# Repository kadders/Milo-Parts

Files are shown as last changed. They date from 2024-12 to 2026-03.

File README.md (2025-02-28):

# Milo Parts Collection

This repository contains various Milo parts and and tooling in STEP file format.

## Vices, Components & Workholding

- [Z-Y Rail Nut v7](T-nuts/Z-Y%20Rail%20Nut%20v7.step) - Rail nut component for Z and Y axis mounting
- [Vice Angle Plate v6](Vices/Angle%20Vice%20Plate/Vice%20Angle%20Plate%20v6.step) - Angle plate for Inception Vice
- [Vice Angle Plate v5](Vices/Angle%20Vice%20Plate/Vice%20Angle%20Plate%20v5.step) - Angle plate for SMW Vice (use with soft jaws)
- [Soft Jaws](Vices/Soft-Jaws/Soft%20Jaws.step) - Protective soft jaws for workholding
- [Jaw Face](Vices/jaw-faces/Jaw%20Face.step) - Replacement face plates for machine vise jaws
- [Vice Collection](Vices/Vice%20Collection.step) - Complete collection of vice bases and vice faces
### Material Requirements

See [Bill of Materials](BOM.md) for detailed material requirements and quantities.

## Tooling & Cutting Tools

- [Tooling](tools/.tools) - Tooling Library Based off the tools from the LDO kit as well as some additional tools.

- For comprehensive information regarding speeds, feeds, and the tooling utilized, please refer to the README files of the respective project repositories.

## Contributing

Feel free to submit issues or pull requests if you have improvements or modifications to any of the parts.

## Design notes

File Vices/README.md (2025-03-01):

# Vices Documentation

This directory contains various vice components and their respective STEP files for reference and use.

## Available Vice Parts
- [Angle Vice Plate](Angle%20Vice%20Plate/) - A plate designed for setting up angles on the vices.
- [Soft Jaws](Soft-Jaws/) - Protective soft jaws for workholding.
- [Jaw Face](jaw-faces/) - Replacement face inserts for vise jaws.
- [Vice Collection](vice-collection/) - A complete collection of vice bases and vice jaws (both small and large) as well as a few other components.

## Additional Documentation

- For detailed operation instructions for the Soft Jaws, refer to the [Soft Jaws README](Soft-Jaws/README.md).

(More documentation will be added as I get time)

Feel free to explore the files and documentation for more information on each component.

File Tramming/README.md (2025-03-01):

# Tramming Tool Documentation

## Tramming Tool
- **Quantity**: 1 piece
- **Stock Material**: ABS/PLA (I used ABS)
- **Print Orientation**: Flat Side down, the 4 holes on the side of the part facing up from the bed.
- **Fasteners**:
  - 2x M5x8mm Ball point grub screw (For securing one or more Dial Indicators)
  - 1x 5mm rod (threaded as one end ~6mm) (For securing the Tramming Tool to the spindle collet)
  - 1x 5mm collet (For holding the 5mm rod in place in the spindle, you might be able to get away with a 6mm collet)

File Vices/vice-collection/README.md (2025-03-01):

# Vice Collection Documentation

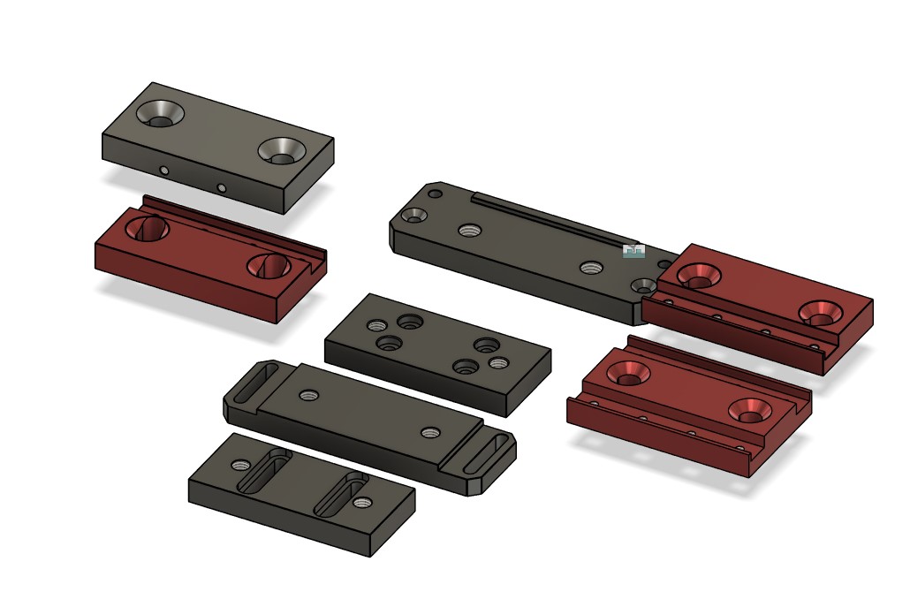
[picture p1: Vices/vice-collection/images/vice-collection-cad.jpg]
Vice Collection CAD Model


## Overview
The Vice Collection includes a complete set of vice bases and vice jaws (both small and large) designed for precision workholding in machining operations. These components provide reliable clamping force while maintaining accuracy for various machining tasks.

## Components
- **Vice Bases**:
  - **Small Sliding Base**: Compact sliding foundation for smaller workpieces
  - **Large Sliding Base**: Full-sized sliding foundation for larger projects
  - **Small Rigid Base**: Fixed compact base for maximum stability with smaller stock footprint.
  - **Large Rigid Base**: Fixed full-sized base for maximum stability with larger stock footprint.
- **Vice Jaws**: For holding larger workpieces

## Material Requirements
- **Vice Bases**: Aluminum 6061-T6 (for lightweight rigidity and excellent machinability)
   - **Small Base**: 25x50x100mm
   - **Large Base**: 50x50x150mm
- **Vice Jaws**: Aluminum 6061-T6 (for lightweight rigidity and excellent machinability)
   - **Jaws**: 25x50x100mm
- **Double Jaws**: Aluminum 6061-T6 (for lightweight rigidity and excellent machinability)
   - **Double Jaws**: 25x75x100mm
- **Fasteners**: 
  - M10x30mm Socket Head Cap Screws (for mounting vice jaws to vice base)
  - M5x12mm Socket Head Cap Screws (for mounting jaw faces, these are called out in the jaw face documentation)

## Features
- Compatible with [Soft Jaws](../Soft-Jaws/) for delicate parts
- Replaceable [Jaw Faces](../jaw-faces/) for when surfaces become worn
- Can be used with the [Angle Vice Plate](../Angle%20Vice%20Plate/) for angled setups

## Installation Instructions
1. Clean the machine table surface thoroughly
2. Align the vice base with T-slots on the machine table
3. Secure using appropriate T-slot nuts and bolts
4. Verify the vice is properly aligned using a dial indicator
5. Install desired jaw faces as needed for the specific operation

## Maintenance
- Regularly clean and lubricate moving parts
- Check for wear on jaw faces and replace as needed
- Verify alignment periodically to ensure continued precision
- Remove chips and debris after each use

## Machining Resources
Machining resources for the vice collection is currently in the works and will be added soon.

## Additional Resources
For further information on other vice components, please refer to the [Vices Documentation](../README.md).

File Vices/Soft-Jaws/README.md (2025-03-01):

# Soft Jaws Documentation

## Overview
The Soft Jaws are designed to provide gentle but secure workholding for delicate or finished parts. They protect workpieces from marring or damage that might occur with standard metal jaws, while still maintaining precision during machining operations.

## Material Requirements
- **Quantity**: 2 pieces (1 pair)
- **Stock Material**: Aluminum 6061-T6 (recommended for durability and precision)
- **Fasteners**: 
  - 2x M10x30mm Counter-Sunk Screws (for mounting to vice, per jaw)

## Features
- Non-marring surface for delicate workpieces
- Custom profiles can be machined into the jaws for specific part geometries
- Compatible with the [Vice Collection](../vice-collection/) vices
- Replaceable design for when jaws become worn or damaged

## Installation Instructions
1. Remove the existing jaw faces from the vise.
2. Align the soft jaws with the mounting holes on the vice.
3. Secure using the M10x30mm Counter-Sunk Screws.
4. Ensure the jaws are properly seated and tightened before use.

## Customization
The soft jaws can be machined to create custom profiles for specific workpieces:
- Use the machining resources provided in [Machining Resources.md](Machining%20Resources.md) for tooling and machining steps that worked well for the soft jaws.
- Follow the recommended toolpaths and settings for optimal results
- Consider creating multiple sets of soft jaws for different workpiece geometries

## Maintenance
- Regularly inspect the soft jaws for wear, damage, or embedded chips
- Clean the jaw surfaces after each use to prevent material buildup
- Replace when worn or damaged to maintain precision in workholding

## Additional Resources
For further information on other vice parts, please refer to the [Vices Documentation](../README.md).

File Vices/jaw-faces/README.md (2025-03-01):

# Jaw Faces Documentation

## Overview
The Jaw Faces are replacement face plates designed for the [Vice Collection](../Vice%20Collection.step) and SMW Vices. They provide a secure and stable surface for workholding, ensuring precision and accuracy during machining operations.

## Material Requirements
- **Quantity**: 1 piece
- **Stock Material**: Aluminum 6061-T6 (100mm x 25mm x 50mm)
- **Fasteners**: 
  - 4x M5x10mm Socket Head Cap Screws (for mounting to vice, per jaw face)

## Installation Instructions
1. Remove the existing jaw faces from the vise.
2. Align the new jaw face with the mounting holes.
3. Secure the jaw face using the appropriate fasteners.
4. Ensure the jaw face is flush with the vise for optimal performance.

## Maintenance
- Regularly inspect the jaw faces for wear and damage.
- Clean the jaw faces after each use to prevent material buildup.
- Replace jaw faces as needed to maintain precision in workholding.

## Additional Resources
For further information on operation and usage, please refer to the [Vices Documentation](../README.md).

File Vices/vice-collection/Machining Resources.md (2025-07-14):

# Top Jaw Documentation

## Operation Overview
- **Operation Name:** Face1
- **Toolpath Type:** Linearized circular move - low memory mode enabled

## Operation 1 Details

### Tool 1: 3 Flute DLC
- **Tool Number:** T9
- **Tool Size:** 6mm
- **RPM:** 15,000
- **Feed Rate:** 333.3 mm/min (for Z movement)
- **Operation Type:** Face Milling with Adaptive Pass
- **Coolant:** Mist (M7)
- **Variable Spindle Speed Control:** Enabled (P4000 V200)
- **Adaptive Pass:** Involves multiple passes with complex contour following, allowing for efficient material removal while maintaining consistent engagement with the workpiece.

### Tool 2: 4.2mm Drill
- **Tool Number:** T11
- **Tool Size:** 4.2mm
- **RPM:** 12,000
- **Feed Rate:** Not specified in the provided G-code.
- **Operation Type:** Drilling
- **Coolant:** Mist (M7)
- **Variable Spindle Speed Control:** Enabled (P4000 V200)

### Tool 3: Double Flute 3mm Ball
- **Tool Number:** T2
- **Tool Size:** 3mm
- **RPM:** 10,000
- **Feed Rate:** Not specified in the provided G-code.
- **Operation Type:** Scallop
- **Coolant:** Mist (M7)
- **Variable Spindle Speed Control:** Enabled (P4000 V200)

### Tool 4: Chamfer Mill
- **Tool Number:** T6
- **Tool Size:** 6mm
- **RPM:** 20,000
- **Feed Rate:** 333.3 mm/min
- **Operation Type:** 2D Chamfer
- **Coolant:** Mist (M7)
- **Variable Spindle Speed Control:** Enabled (P4000 V200)

### Tool 5: M5x0.8mm Thread Mill
- **Tool Number:** T17
- **Tool Size:** M5x0.8mm
- **RPM:** 6,000
- **Feed Rate:** Not specified in the provided G-code.
- **Operation Type:** Thread Milling
- **Coolant:** Mist (M7)
- **Variable Spindle Speed Control:** Enabled (P4000 V200)

## Operation 2 Details

### Tool 1: 3 Flute DLC
- **Tool Number:** T9
- **Tool Size:** 6mm
- **RPM:** 15,000
- **Feed Rate:** 333.3 mm/min (for Z movement)
- **Operation Type:** Face Milling with Adaptive Pass
- **Coolant:** Mist (M7)
- **Variable Spindle Speed Control:** Enabled (P4000 V200)
- **Adaptive Pass:** Involves multiple passes with complex contour following, allowing for efficient material removal while maintaining consistent engagement with the workpiece.

### Tool 2: Chamfer Mill
- **Tool Number:** T6
- **Tool Size:** 6mm
- **RPM:** 20,000
- **Feed Rate:** 333.3 mm/min
- **Operation Type:** 2D Chamfer
- **Coolant:** Mist (M7)
- **Variable Spindle Speed Control:** Enabled (P4000 V200)

## Summary of Operations
1. **Initial Setup and Probing:**
   - Probes reference surface.
   - Uses WCS 1 (G54).
   - Probes origin in current WCS.
   - Enables rotation compensation.

2. **Main Operation (Tool 1 - T9):**
   - **Type:** Face Milling with Adaptive Pass
   - **RPM:** 15,000
   - **Feed Rate:** 333.3 mm/min
   - **Operation:** Multiple passes with complex contour following, including adaptive milling strategies.

3. **Secondary Operations (Tool 2 - T11):**
   - **Type:** Drilling
   - **RPM:** 12,000
   - **Feed Rate:** Not specified.
   - **Operation:** Drilling operations as needed.

4. **Additional Operations (Tool 3 - T2):**
   - **Type:** Scallop
   - **RPM:** 10,000
   - **Feed Rate:** Not specified.
   - **Operation:** Scalloping as part of the machining process.

5. **Chamfer Operation (Tool 4 - T6):**
   - **Type:** 2D Chamfer
   - **RPM:** 20,000
   - **Feed Rate:** 333.3 mm/min
   - **Operation:** Chamfering around the perimeter.

6. **Threading Operation (Tool 5 - T17):**
   - **Type:** Thread Milling
   - **RPM:** 6,000
   - **Feed Rate:** Not specified.
   - **Operation:** Thread milling as required.

## Additional Notes
- The operation includes extensive safety checks and spindle controls.
- The G-code is designed for a specific firmware configuration (RRF) and includes automatic probing and work coordinate system management.
- The operation features multiple tool changes and complex machining paths.

# Machining Details for Large Sliding Base - Op1

### Steps:
1. **Initial Setup:**
   - Probes reference surface.
   - Switch to WCS 1 (G54).
   - Probes origin in current WCS.
   - Enables rotation compensation.

2. **Starting Position:**
   - Move to starting position in X and Y: `G0 X54.01 Y-2.395`
   - Move to starting position in Z: `G0 Z15.0`

3. **Engage Tool:**
   - Move down to Z position: `G1 Z-2.1 F333.3`

4. **Face Milling Operation:**
   - Perform linearized circular moves to mill the face:
     - `G1 X54.003 Z-2.194 F2000.0`
     - Continue with a series of linear moves to create the desired contour.

5. **Adaptive Pass:**
   - Execute adaptive milling strategies with multiple passes to efficiently remove material while maintaining consistent engagement with the workpiece.

6. **Final Positioning:**
   - Return to Z position: `G0 Z5.0`
   - Move to a new X and Y position: `G0 X10.896 Y138.867`
   - Engage tool again: `G1 Z-7.175 F333.3`
   - Perform additional milling operations as needed.

### Tool 1: 3 Flute DLC
- **Tool Number:** T9
- **Tool Size:** 6mm
- **RPM:** 15,000
- **Feed Rate:** 333.3 mm/min (for Z movement)
- **Operation Type:** Face Milling with Adaptive Pass
- **Coolant:** Mist (M7)
- **Variable Spindle Speed Control:** Enabled (P4000 V200)

### Tool 2: Single Flute 3mm
- **Tool Number:** T1
- **Tool Size:** 3mm
- **RPM:** Not specified in the G-code.
- **Feed Rate:** Not specified in the G-code.
- **Operation Type:** Not explicitly defined in the provided G-code.
- **Coolant:** Mist (M7)
- **Variable Spindle Speed Control:** Enabled (P4000 V200)

#### Steps:
1. **Engage Tool:**
   - Tool is passed to firmware but not explicitly used in the provided G-code.

### Tool 3: Chamfer Mill
- **Tool Number:** T6
- **Tool Size:** 6mm
- **RPM:** Not specified in the G-code.
- **Feed Rate:** Not specified in the G-code.
- **Operation Type:** Chamfering
- **Coolant:** Mist (M7)
- **Variable Spindle Speed Control:** Enabled (P4000 V200)

#### Steps:
1. **Engage Tool:**
   - Tool is passed to firmware but not explicitly used in the provided G-code.

## Summary of Operations
1. **Initial Setup and Probing:**
   - Probes reference surface.
   - Uses WCS 1 (G54).
   - Probes origin in current WCS.
   - Enables rotation compensation.

2. **Main Operation (Tool 1 - T9):**
   - **Type:** Face Milling with Adaptive Pass
   - **RPM:** 15,000
   - **Feed Rate:** 333.3 mm/min
   - **Operation:** Multiple passes with complex contour following, including adaptive milling strategies.

3. **Additional Operations:**
   - **Tool 2 (Single Flute 12mm):** Not explicitly used in the operation.
   - **Tool 3 (Chamfer Mill):** Not explicitly used in the operation.

## Additional Notes
- The operation includes extensive safety checks and spindle controls.
- The G-code is designed for a specific firmware configuration (RRF) and includes automatic probing and work coordinate system management.
- The operation features multiple tool changes and complex machining paths.

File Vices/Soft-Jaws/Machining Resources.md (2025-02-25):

# Vice Jaw Operation 1 Overview

## Tool Changes and Operations

### Tool 9 - 3 Flute DLC (6mm)
- **RPM**: 15,000
- **Feed Rate**: 2,000 mm/min
- **Operation**: Adaptive clearing
- **Coolant**: Mist (M7)
- **Variable Spindle Speed Control**: Enabled (P4000 V200)

### Tool 3 - Single Flute (12mm)
- **RPM**: 20,000
- **Feed Rate**: 1,000 mm/min
- **Operation**: Adaptive clearing
- **Coolant**: Mist (M7)
- **Variable Spindle Speed Control**: Enabled (P4000 V200)

### Tool 2 - Double Flute 17mm Ball
- **RPM**: 20,000
- **Feed Rate**: 960 mm/min
- **Operation**: Scallop
- **Coolant**: Mist (M7)
- **Variable Spindle Speed Control**: Enabled (P4000 V200)

### Tool 6 - Chamfer Mill (6mm)
- **RPM**: 20,000  
- **Feed Rate**: 2,000 mm/min
- **Operation**: 2D Chamfer
- **Coolant**: Mist (M7)
- **Variable Spindle Speed Control**: Enabled (P4000 V200)

## Process Overview
1. Initial setup and probing
   - Probes reference surface
   - Uses WCS 1 (G54)
   - Probes origin in current WCS
   - Enables rotation compensation

2. Main Adaptive Operation (Tool 9)
   - Multiple adaptive clearing passes
   - Complex contour following
   - Multiple Z-level operations

3. Secondary Adaptive Operations (Tool 3 & Tool 2)
   - Additional adaptive clearing passes
   - Complex contour following
   - Multiple Z-level operations

4. Chamfer Operation (Tool 6)
   - 2D chamfering around the perimeter
   - Single pass at -3mm depth

## Safety Features
- Firmware version check (v0.5.0-rc1)
- Tool details passed to firmware
- Spindle acceleration monitoring
- Variable speed control for vibration reduction
- Coolant control
- Automatic parking between operations

## Notes
- File includes extensive safety checks and spindle controls
- Uses RRF firmware-specific features
- Includes automatic probing and work coordinate system management
- Multiple parking and tool change operations
- Comprehensive coolant and spindle speed management

# Vice Jaw Operation 2 Overview

## Tool Changes and Operations

### Tool 1 - 3 Flute DLC (3mm)
- **RPM**: 15,000
- **Feed Rate**: 2,000 mm/min
- **Operation**: Adaptive clearing
- **Coolant**: Mist (M7)
- **Variable Spindle Speed Control**: Enabled (P4000 V200)

### Tool 6 - Chamfer Mill (3mm)
- **RPM**: 20,000
- **Feed Rate**: 2,000 mm/min
- **Plunge Feed**: 333.3 mm/min
- **Operation**: 2D Chamfer
- **Coolant**: Mist (M7)
- **Variable Spindle Speed Control**: Enabled (P4000 V200)

## Process Overview
1. Initial setup and probing
   - Probes reference surface
   - Uses WCS 1 (G54)
   - Probes origin in current WCS
   - Enables rotation compensation

2. Main Adaptive Operation (Tool 1)
   - Multiple adaptive clearing passes
   - Complex contour following
   - Multiple Z-level operations at -3.9mm, -8.4mm, -17.7mm depths

3. Chamfer Operation (Tool 6)
   - 2D chamfering around the perimeter
   - Single pass at -10.449mm depth
   - Includes both external and internal feature chamfering

## Safety Features
- Firmware version check (v0.5.0-rc1)
- Tool details passed to firmware
- Spindle acceleration monitoring
- Variable speed control for vibration reduction
- Coolant control
- Automatic parking between operations

## Notes
- Operation 2 focuses on the opposite side of the vice jaw
- Includes deeper cutting operations than Operation 1
- Multiple Z-level passes for material removal
- Comprehensive safety checks and spindle controls
- Uses RRF firmware-specific features
- Includes automatic probing and work coordinate system management

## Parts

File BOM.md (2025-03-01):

# Bill of Materials

## Vices & Workholding Components

### Jaw Faces
- Quantity: 3 pieces
- Stock Material: 25x50x100mm (per jaw face, up to three)
- Fasteners:
  - 8x M5x12 (For attaching the jaw faces to the vice jaw tops)
- Location: [Jaw Face](Vices/jaw-faces/Jaw%20Face.step)

### Soft Jaws
- Quantity: 1 set
- Stock Material: 25x50x100mm (Per Soft Jaw)
- Fasteners:
  - 2x M10x30 (For attaching the soft jaws to the vice jaw tops)
- Location: [Soft Jaws](Vices/Soft-Jaws/Soft%20Jaws.step)

### Vice Angle Plates
- Quantity: 1 piece
- Stock Material: 25x50x100mm
- Fasteners:
  - 4x M5x12 (For attaching the vice angle plate to the vice jaw tops)
  - 2x M3 Shoulder Bolt (4mm shoulder) for attaching the angle bars to the angle plate
  - 2x 2mm pin (For setting the angle of the angle bars)
- Location: 
  - [Inception Vice Angle Plate](Vices/Angle%20Vice%20Plate/Vice%20Angle%20Plate%20v6.step)
  - [SMW Vice Angle Plate](Vices/Angle%20Vice%20Plate/Vice%20Angle%20Plate%20v5.step)

### Vice Collection
- Quantity: 1 set (2 vice bases, 2 vice jaw tops)
- Stock Material: 
  - 25x50x100mm (For the vice bases and jaw tops)
  - 25x50x150mm for larger components (Large Sliding Base and Large rigid base)
- Fasteners:
  - 4x M10x30 (For attaching the vice jaw tops to the base)
  - 8x M5x12 (For attaching the jaw faces to the vice jaw tops)
- Note: Complete collection of vice bases and vice faces
- Location: [Vice Collection](Vices/Vice%20Collection.step)

### T-Nuts
- Quantity: As needed
- Stock Material: 25x50x100mm (can fit 4 T-nuts, two large and two small)
- Fasteners:
  - 16x M5x8 (For attaching the T-nuts, and also for fixturing the workpiece, if desired)
- Note: Includes supplemental workholding fixture in STEP file
- Location: [Z-Y Rail Nut](T-nuts/Z-Y%20Rail%20Nut%20v7.step)

### Tramming Tool
- Quantity: 1 piece
- Stock Material: 25x50x100mm (for the main body)
- Fasteners:
  - 2x M5x8mm Ball point grub screw (For securing one or more Dial Indicators)
  - 1x 5mm rod (threaded as one end ~6mm) (For the securing the Tramming Tool to the spindle collet)
  - 1x 5mm collet (For holding the 5mm rod in place in the spindle, you might be able to get away with a 6mm collet)
- Location: [Tramming Tool](Tramming/Tramming%20Tool.step)

## Reference
Material requirements sourced from README.md:

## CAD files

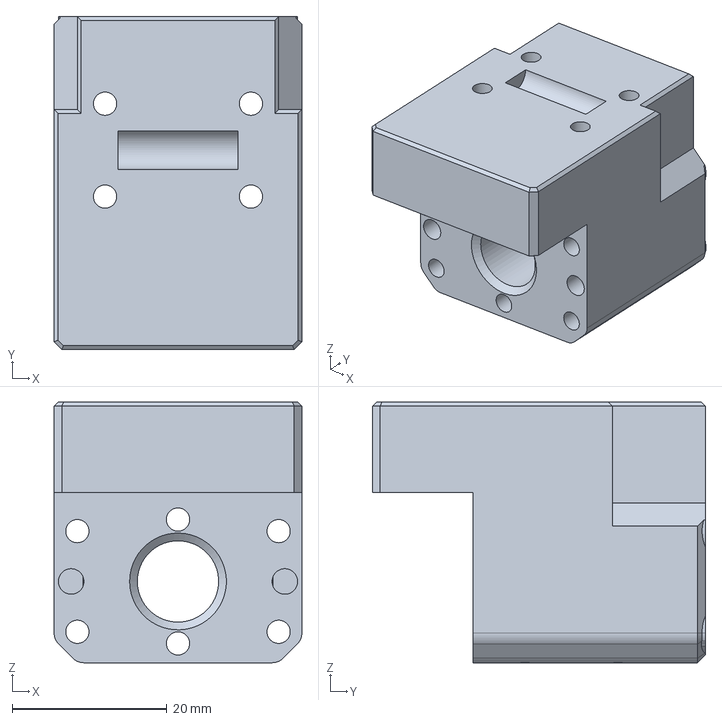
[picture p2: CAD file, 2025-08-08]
v1.6/AB Nut/ThrED-AB-Block-Assembly v39 v6.step
32.0 x 43.0 x 33.7 mm

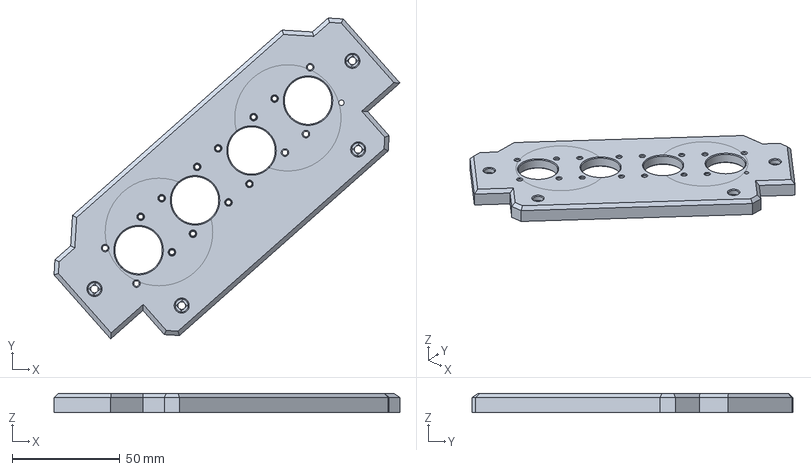
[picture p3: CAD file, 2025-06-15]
Casa/Electronics/Electronics passthru v6.step
160.8 x 149.1 x 9.00 mm

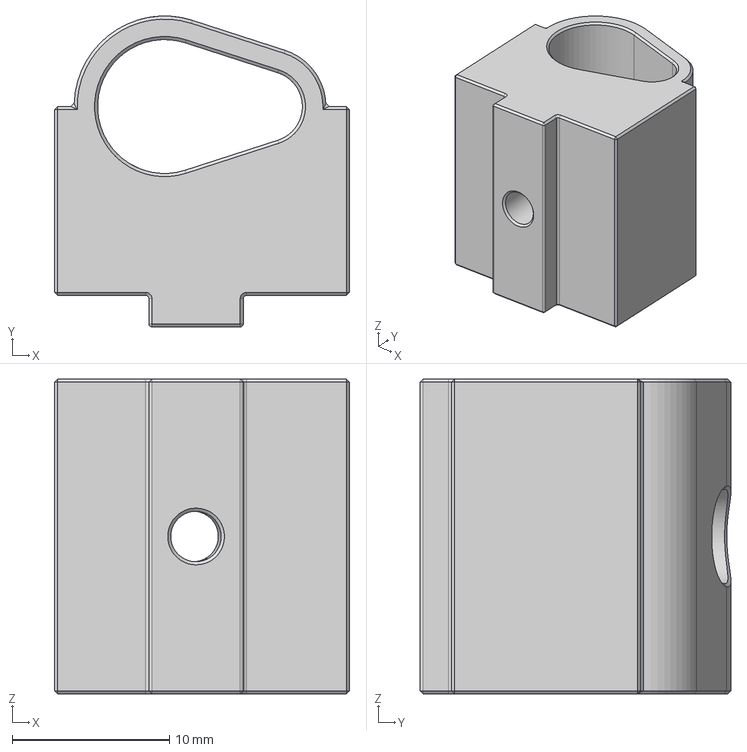
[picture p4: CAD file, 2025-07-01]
Casa/Misc/Air Line Holder.step
18.8 x 19.7 x 20.0 mm

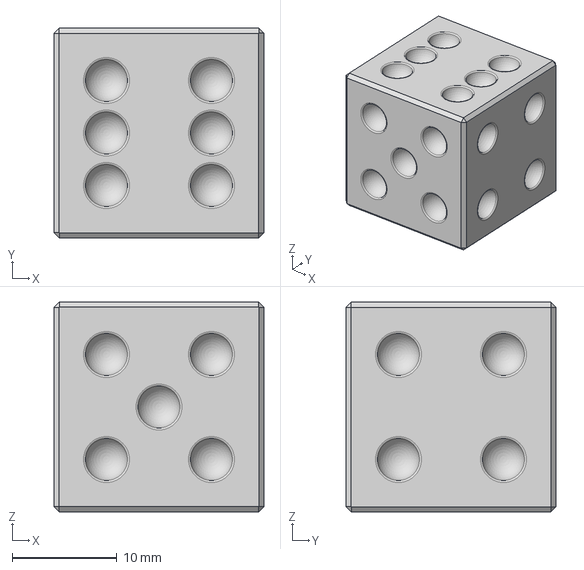
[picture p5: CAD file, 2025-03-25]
Dice/Dice.step
20.0 x 20.0 x 20.0 mm

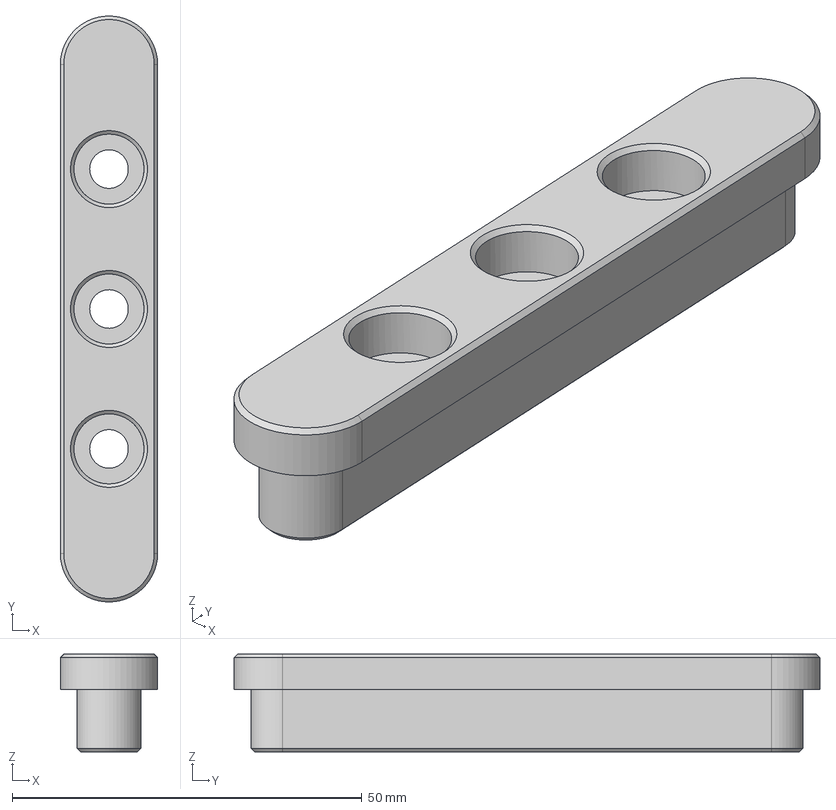
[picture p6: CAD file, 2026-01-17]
Hold Downs/SMW Hold Down.step
13.9 x 83.8 x 14.0 mm

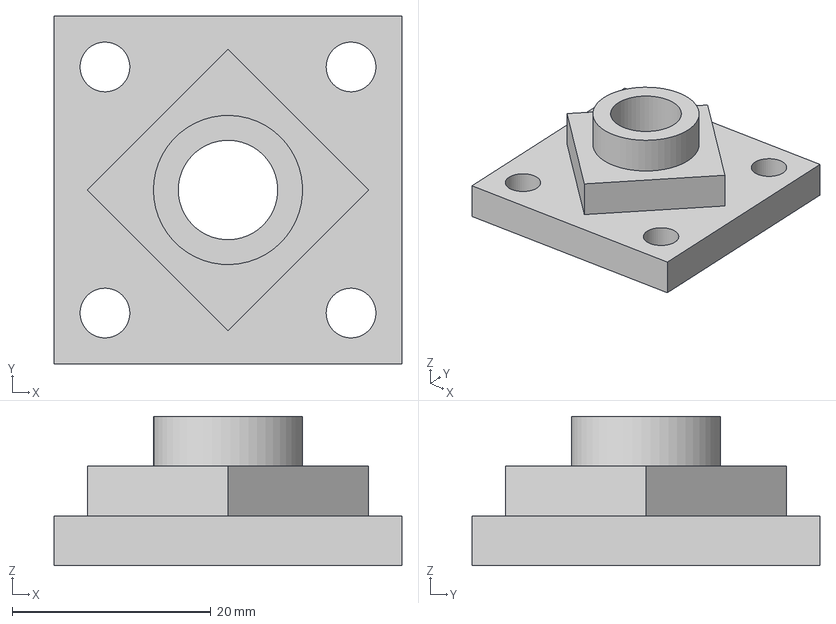
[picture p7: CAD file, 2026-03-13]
Test Part/Test BenCNC.step
35.0 x 35.0 x 15.0 mm

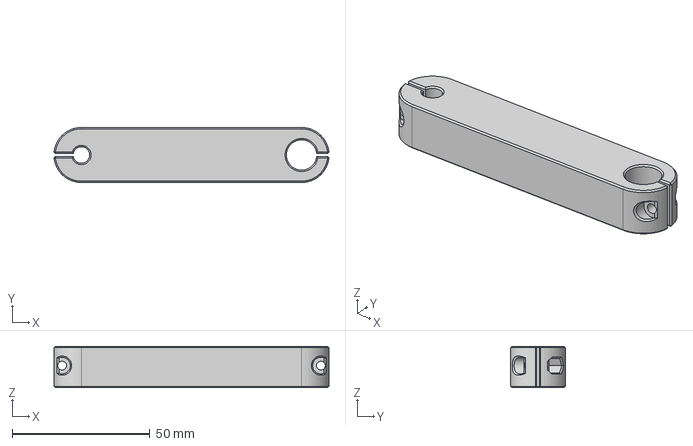
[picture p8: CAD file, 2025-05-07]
Tramming/Tram Swing Arm.step
99.9 x 20.0 x 15.0 mm

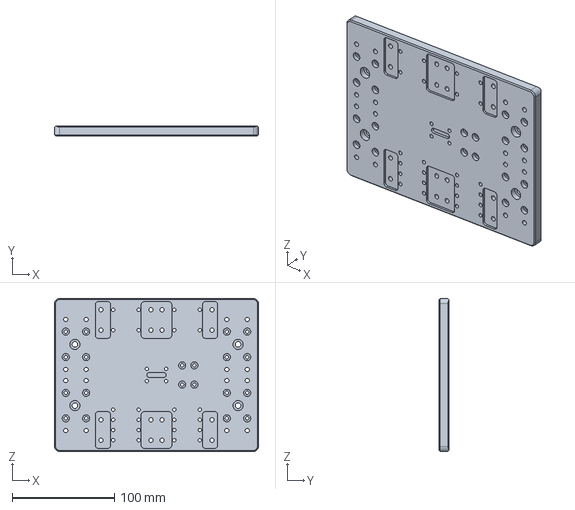
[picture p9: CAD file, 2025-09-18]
v1.6/X-Y Joiner Plate/X-to-Y-Joiner-Plate.step
200.0 x 9.60 x 150.0 mm

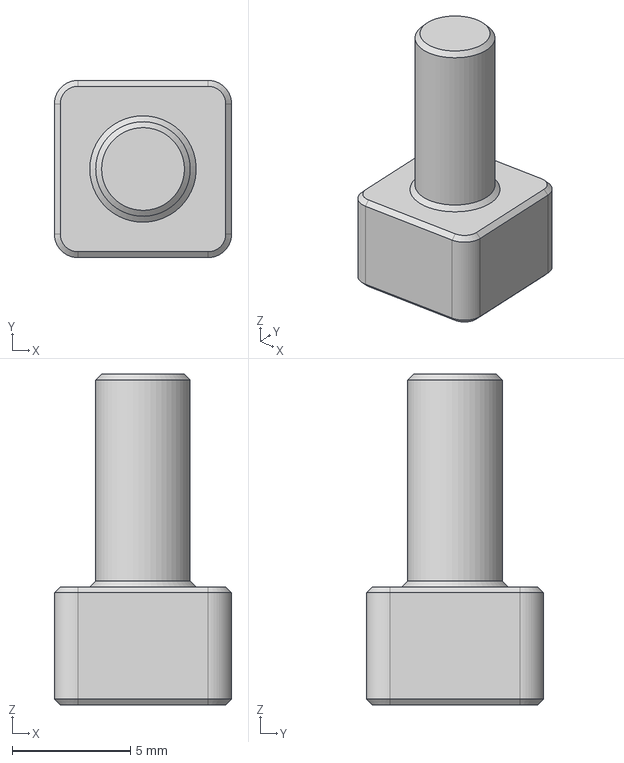
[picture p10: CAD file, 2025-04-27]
Vices/Angle Vice Plate/Angle Plate Stop.step
7.50 x 7.50 x 14.0 mm

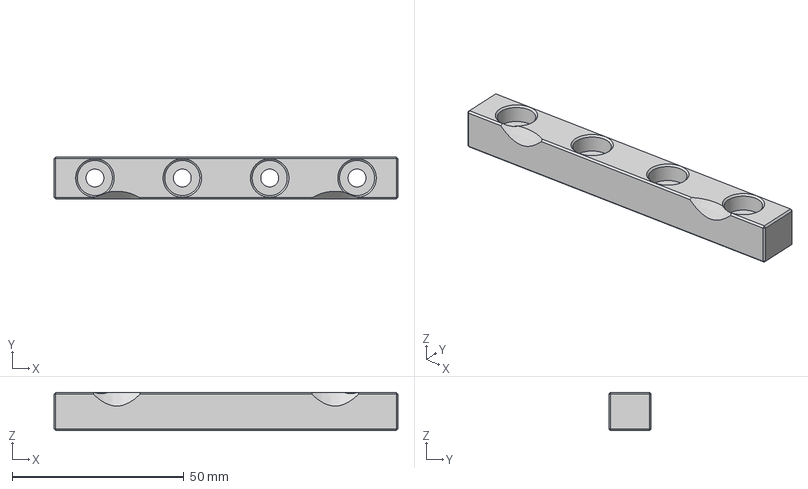
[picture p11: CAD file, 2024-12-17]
Vices/jaw-faces/Jaw Face.step
100.0 x 12.3 x 11.1 mm

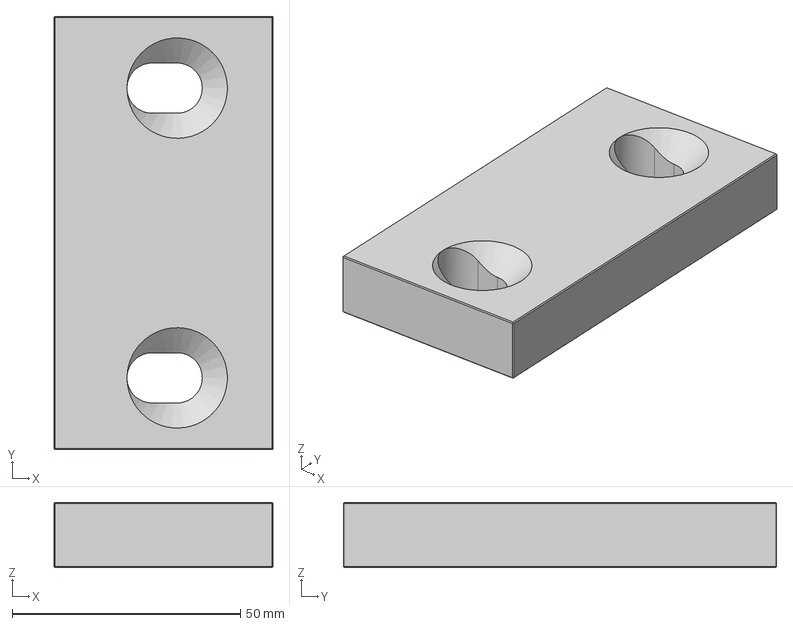
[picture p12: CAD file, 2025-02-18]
Vices/Soft-Jaws/Soft Jaws.step
48.0 x 95.0 x 14.4 mm

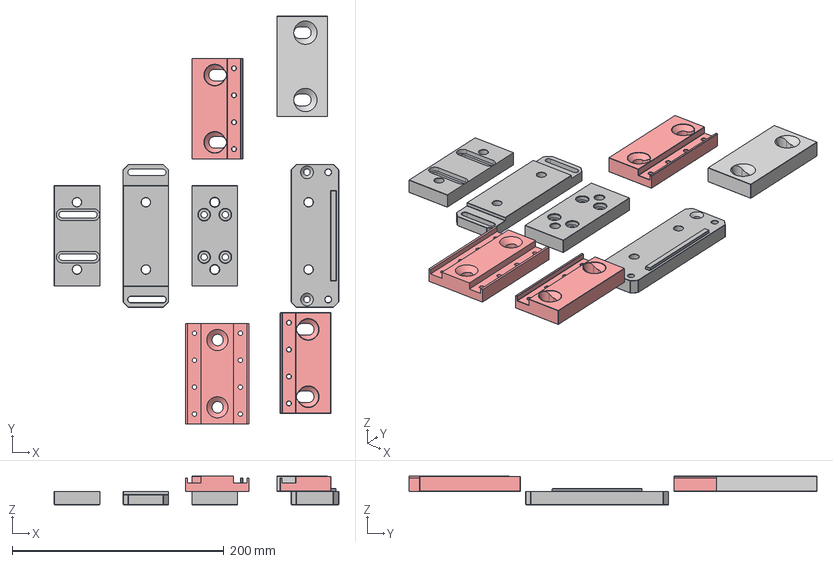
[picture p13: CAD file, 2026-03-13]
Vices/vice-collection/Vices.step
268.5 x 385.0 x 27.1 mm
SlidingBase
Jaw x 2
Soft Jaw
RigidBase
Small Sliding Base
Small Rigid Base
Double Sided Jaw

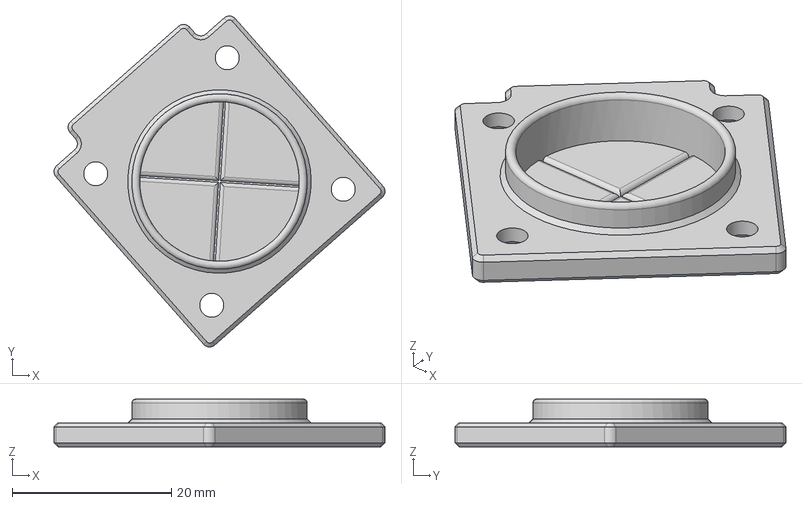
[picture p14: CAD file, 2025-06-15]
Casa/Electronics/Electronics passthru Grommet.step
41.5 x 41.5 x 6.00 mm

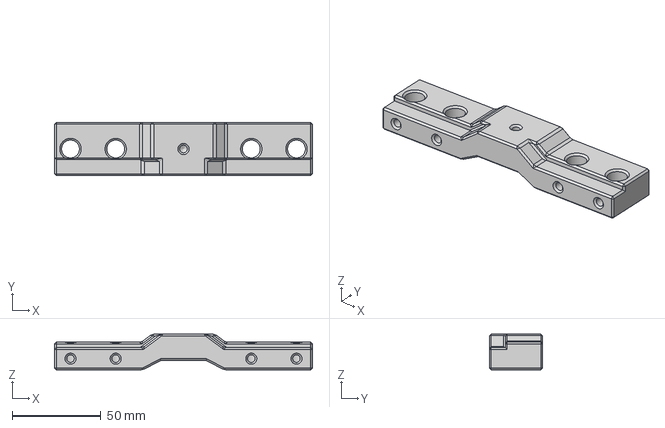
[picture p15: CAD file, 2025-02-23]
Tramming/Tramming Tool v5.step
145.0 x 30.0 x 20.0 mm

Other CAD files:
Vices/Angle Vice Plate/Vice Angle Plate.step
Anti-Backlash Nuts/Y/Y Axis Anti Backlash Nut.step
Anti-Backlash Nuts/Z/Z Axis Anti Backlash Nut.step
Probe-Nut/Probe Nut.step
T-nuts/Z-Y Rail Nut v7.step
Test Part/Test BenCNC v1.step

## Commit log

2024-12-17 Adding in Jaw Face STEP file
    [Jaw Face.step]
2025-01-25 Adding in initial t-nuts file (still in work)
    [Z-Y Rail Nut.step]
2025-01-30 Adding in Updated STEP for inserts, refining holes and tolerances
    [Z-Y Rail Nut v7.step, Z-Y Rail Nut.step]
2025-02-17 Adding in Draft Angle Vice Plates
    [Vice Angle Plate v5.step, Vice Angle Plate v6.step]
2025-02-18 Adding in Soft Jaws Models for SMW
    [Soft Jaws.step]
2025-02-20 Adding in initial BOM and Updating the README
2025-02-20 Adding in Vice collection with license, updating the BOM and README (#4)
    [Vices.step]
2025-02-23 Adding in Tramming Tool
    [Tramming Tool v5.step]
2025-02-28 Updating BOM for the repo
2025-03-01 Updating BOM and README for Tramming tool
2025-03-05 Adjusting for thread diameter on large rigid base
    [Vices.step]
2025-03-25 Adding in 20mm dice model
    [Dice.step]
2025-04-25 Adding in Modified LDO Anti-Backlash Nuts for Milling
    [Y Axis Anti Backlash Nut.step, Z Axis Anti Backlash Nut.step]
2025-04-27 Adding in changes to Angle plate, reducing complexity of version to conform to Vice ecosystem in the directory, adding in part stop for long and short bars
    [Angle Plate Stop.step, Vice Angle Plate v5.step, Vice Angle Plate v6.step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]
2025-05-07 Adding in a Single side swing arm for tramming
    [Tram Swing Arm.step]
2025-05-07 Updating M3 clearnace holes
    [Tram Swing Arm.step]
2025-06-15 Adding in LP20 passthrough and Grommet designs
    [Electronics passthru Grommet.step, Electronics passthru v6.step]
2025-07-01 Adding in Air Line Holder for attaching to 2020 extrusions
    [Air Line Holder.step]
2025-08-07 Adding in STEP for minor adjustments to M5 hole spacing in the plate to allow for directly mounting to fixated plate on Milo 1.5
    [X-to-Y-Joiner-Plate v3.step]
2025-08-08 Adding in revisions for milling the AB Nut assembly
    [ThrED-AB-Block-Assembly v39 v6.step]
2025-09-18 Updating Joiner Plate
    [X-to-Y-Joiner-Plate v3.step, X-to-Y-Joiner-Plate.step]
2025-11-01 Adding in new CNC Test Part
    [Test BenCNC v1.step]
2026-01-17 Adding in SMW small plate hold downs
    [SMW Hold Down.step]
2026-01-17 Updating dimensions to 20mm from 30mm
    [SMW Hold Down.step]
2026-03-13 Updating the Vice collection and removing the version from BenCNC file
    [Test BenCNC.step, Vices.step]
2026-05-21 Adding in initial (untested) Probe Nut model
    [Probe Nut.step]
